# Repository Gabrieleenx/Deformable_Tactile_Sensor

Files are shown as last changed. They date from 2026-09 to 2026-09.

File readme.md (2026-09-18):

# Deformable In-Hand Slip-Aware Tactile Sensor 

This is the material and guides for the paper "Deformable In-Hand Slip-Aware Tactile Sensor with Integrated Velocity Sensing, Force/Torque and Pressure Map Estimation". You can also find a more popular science presentatin on the entire project https://youtu.be/DqMjxcfm4Ek?si=F0FGEtK1jk1I4O4m

This repo is devided into 3 parts: 
1. build files: this is the files and guide to physically build the sensor 
2. embedded code: this is the code that runs on the sensor
3. code on pc: this is the code on the pc that interfaces with the sensor, it also contains the code for calibrating the sensors. 

A 3D printable version of the gripper used can be found at: https://github.com/Gabrieleenx/Parallel_gripper and the fingers to mount the sensors can be found at "/build_files/fingers_cnc", I CNC them from 6061 aluminium on my own CNC, but they could be ordered from PCBWay.

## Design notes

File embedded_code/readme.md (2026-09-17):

# Embedded code

Here is the source code for the tactile sensors, I compiled it with platformio in vs code. It uses the arduino framework, see the .ini file.

In the main file, you can set the name of the sensor, which is usefull if you have multiple of them. Otherwise it is just to flash the sensor and it will start to send out data. If you send 'n' to it will start to print out its name, if you send 's' to it will start to send data again.

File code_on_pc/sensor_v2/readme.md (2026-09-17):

# Code on PC side

This is the part of the project that is the most messy. It is based on ROS Noetic, which is beyond outdated at this point. But the core part of the code for running the sensors has no real dependence on ROS Noetic and can be easily ported to run with anything that suports USB serial and torch. We have already ported it to another framework which is not based on ROS, but not sure when that will see the light of day (not up to me). If I where to use this, I would probaly rewrite this to ROS2 or what ever your lab is using. I never bothered to update, because it worked and it is the very end of my PhD.   

There are a lot of places in the code where you will need to provide paths to models or bags etc... 

## Interfacing with the sensors

Under "/src/sensor_run_time" there is two sets of code to run the sensors. This I included the code that runs a sensor individually and the code that allows multiple of them to run on for example a gripper (https://github.com/Gabrieleenx/Slip-Aware-Object-Manipulation-with-Parallel-Grippers). 

To run the sensors indiviually you have 
```
rosrun sensor_v2 tactile_sensor_node.py
```
which starts the serial communciation with the sensor.
Then the sensor data is mapped to forces and pressure map with:
```
rosrun sensor_v2 tacitle_mapping_node.py
```

For when I ran it on the gripper I used
```
rosrun sensor_v2 sensors_on_gripper.py
```
this also includes the cross sensor compensation. And mapping:
```
rosrun sensor_v2 sensors_mapping_on_gripper.py
```

## Collecting traning data and training 

First don't blindly follow others code when controlling robots, that includes this code. This code does not have many saftey features so don't trust it! It worked for me, but doesn't mean it will work for you. It is essentially just inverse differential kinematics and some trajectory following with force limits/feedback, I would encurage you to write your own version, it is not many lines of code for controlling a UR3e robot. 

This is to collect the data for training, the setup should look like the figure below:

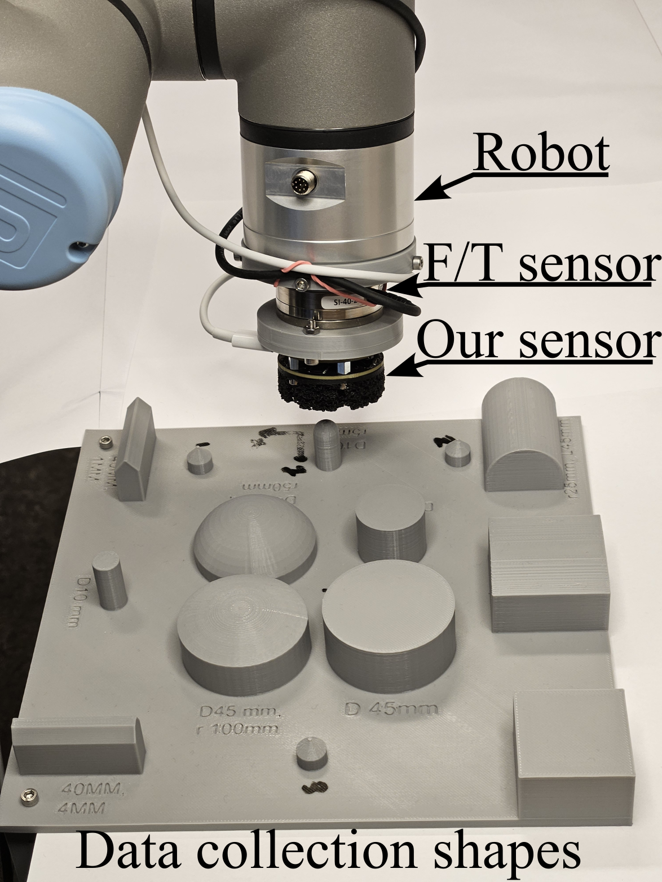
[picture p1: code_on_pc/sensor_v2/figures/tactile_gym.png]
tactile_gym

All 3D printed files are in the bild_files folder. To start the data collection process, there is like robotics classic of 15 scripts to run in terminals. 

```
rosrun rviz rviz -d ~/Documents/Catkin_workspace/catkin_yumi/src/ur_description/launch/ur3_rviz.launch
roslaunch ur_robot_driver ur3e_bringup.launch robot_ip:=192.168.56.3 kinematics_config:=$(rospack find sensor_v2)/etc/robot_calibration.yaml
rosparam load ~/Documents/Catkin_workspace/catkin_yumi/src/sensor_v2/config/ur3_joint_velocity_controller.yaml
rosrun controller_manager spawner --stopped ur3_joint_velocity_controller
rosservice call /controller_manager/switch_controller "{start_controllers: ['ur3_joint_velocity_controller'], stop_controllers: ['scaled_pos_joint_traj_controller'], strictness: 2}"
rosrun netft_utils netft_node --address=192.168.56.5 --sensor_nr=1 # modify to what ever F/T sensors you use, also rezero it!
rosrun sensor_v2 cartesian_velocity_converter_node
roslaunch sensor_v2 tactile_controller.launch 

```

```
rosrun sensor_v2 tactile_sensor_node.py
rosrun sensor_v2 tactile_tf_direct.py
rosrun sensor_v2 calibrate_sensor.py
```
This will ask you to first calibrate the pose, like so:

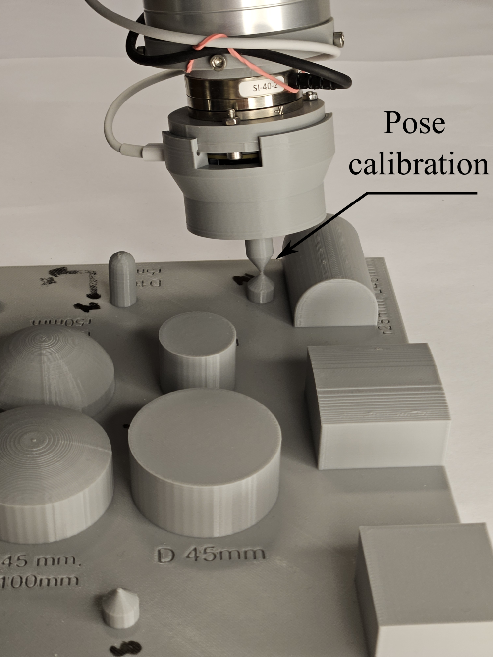
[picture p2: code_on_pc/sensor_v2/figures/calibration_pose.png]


which shows the second calibration pose, 1st is down and 3rd is closest to the camera. This is lead through with the F/T sensor. This will take like 1 hour once started. 

Then do the same to collect the validation data (with fewer pokes).

Once you have two folders with a bunch of bag fiels, we need to extract data and calculate the mesh overlap. This is very so and ineffeicently implemented, so would recomend to do over night. Go to "/data_creation/" and run filter_data.py, and make sure it is pointing to the correct folder with all the data. This will create a data.csv in the folder with the data, do this for both traning and validation foler. 

Then run "filter_out_bad_data.py", it removes some samples that have overlap with no force or the opposie, mby like 30 datapoints in 1900 ish.

We then have the data sets ready for traning a mapping. Under "/learn_mapping/" there is a file called train_mapping.py, point to the training and validation csv files and run the script.

## Calibrate optical sensors

In the mapping scripts there is a sensor config class with the paramters for each optical sensor. These can be found by running calibrate_vel_sensor.py instead of calibrate_sensor.py above. Replace the bag files in "estimate_sensor_pose/data/" with those and run "calculate_sensor_pose.py", this will print out the parameter for each optical sensor. 

I know this is a bit of a messy project and requiers a bit more effort than just run it. But this field of sliding in-hand manipulation is very small and I would not expect many to care to replicate the setup. If that turn out to be wrong, and there is a big interest, then I might try to improve the library.

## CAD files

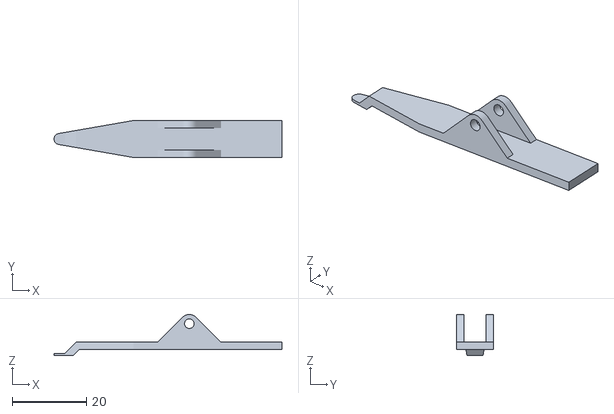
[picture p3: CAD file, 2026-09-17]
build_files/3d_print_files/supporting_files/magnet_place_tool_botom.stl
61.5 x 10.0 x 11.1

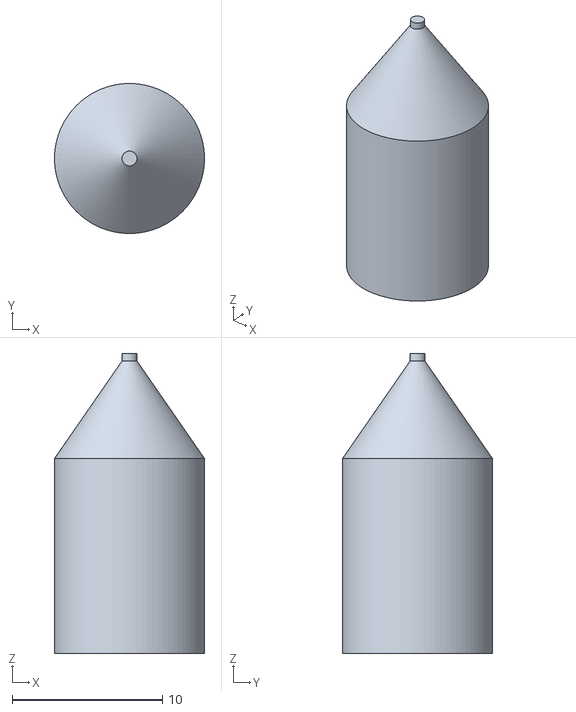
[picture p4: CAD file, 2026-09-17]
build_files/3d_print_files/supporting_files/sensor_v2_data_collection_mount/calibration_tip.stl
10.0 x 10.0 x 20.0

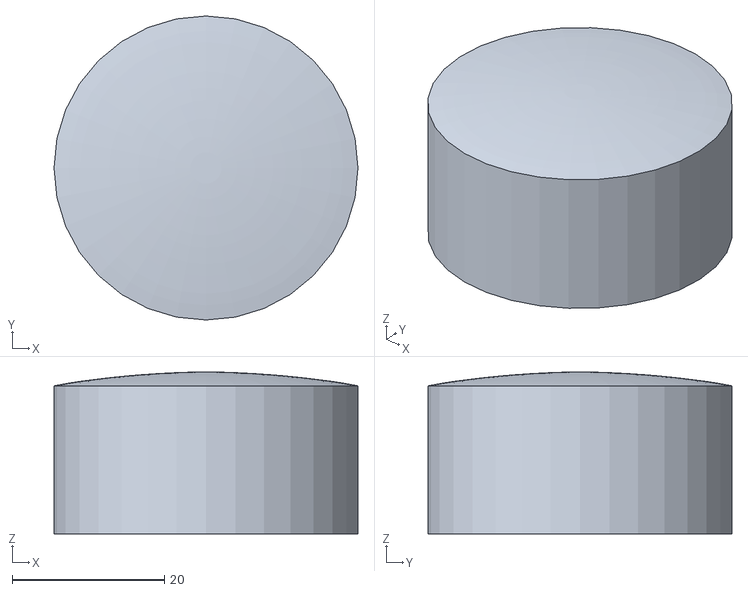
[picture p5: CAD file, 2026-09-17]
code_on_pc/sensor_v2/data_creation/mesh_data/sensor.stl
40.0 x 40.0 x 21.3

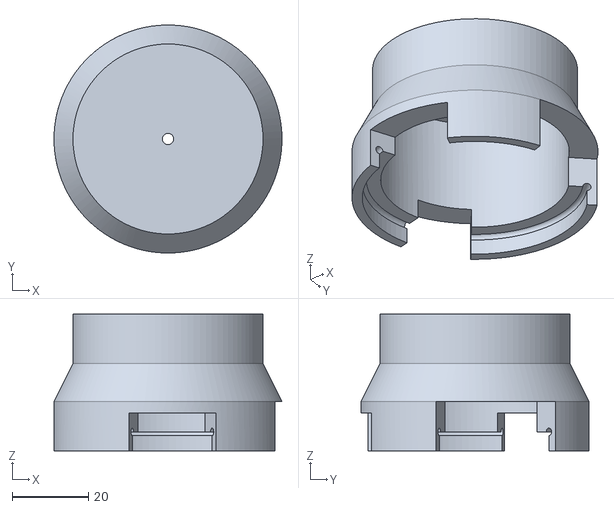
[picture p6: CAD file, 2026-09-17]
build_files/3d_print_files/supporting_files/sensor_v2_data_collection_mount/calibration_sleve.stl
60.0 x 60.0 x 36.0

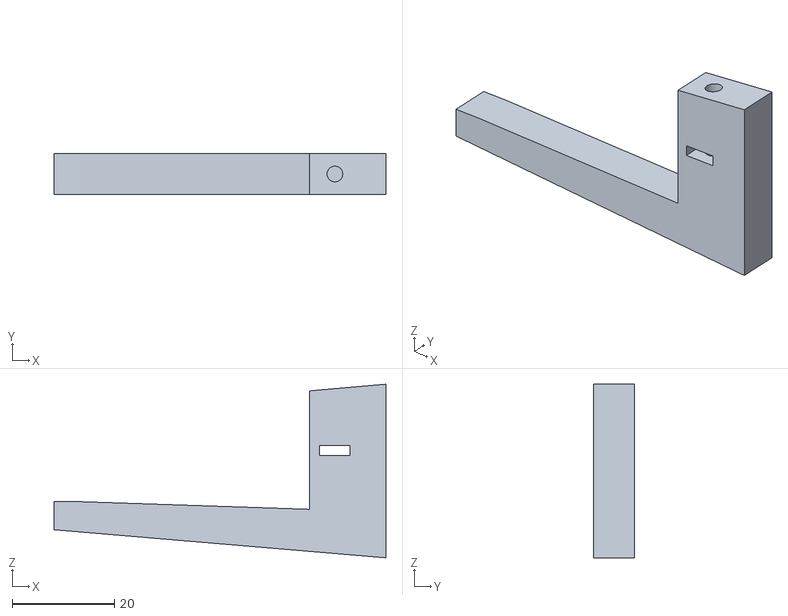
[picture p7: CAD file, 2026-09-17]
build_files/3d_print_files/supporting_files/table_holder.stl
65.0 x 8.00 x 34.0

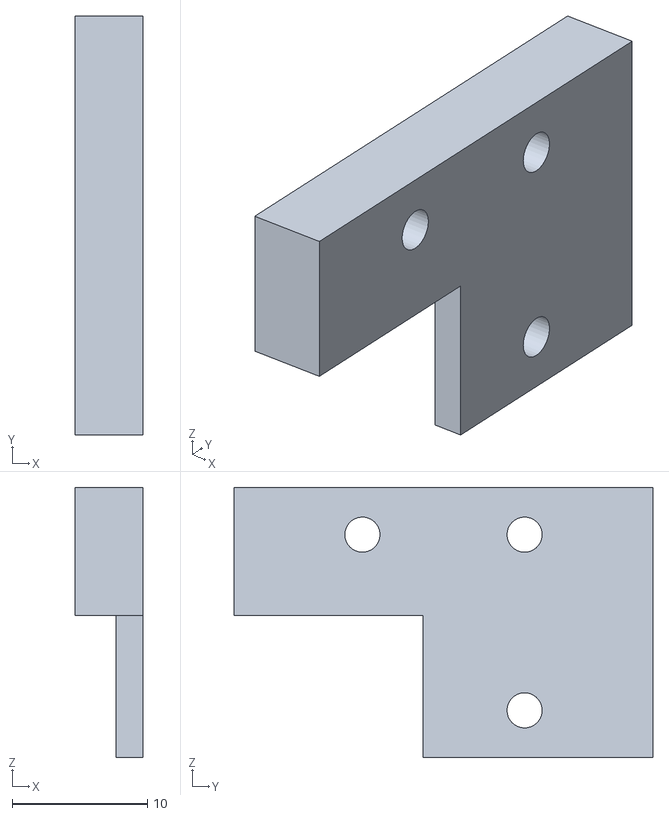
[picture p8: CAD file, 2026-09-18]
build_files/fingers_cnc/finger_sensor_v2_3.stl
5.00 x 31.0 x 20.0

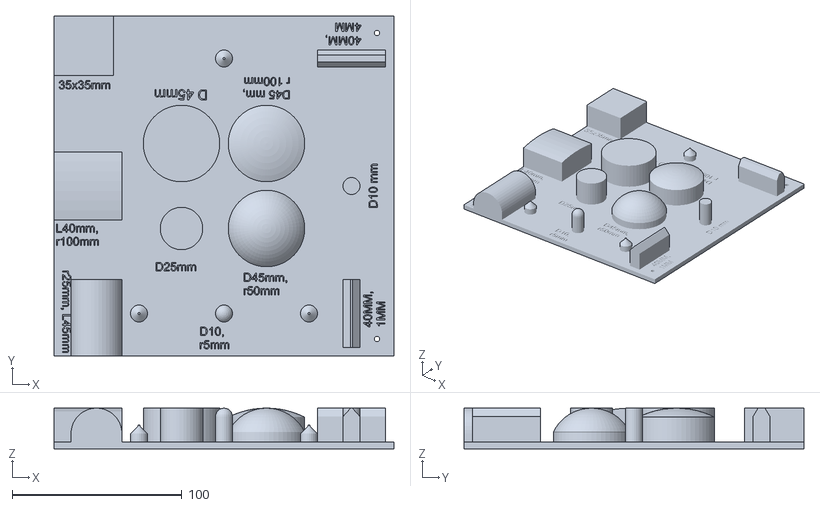
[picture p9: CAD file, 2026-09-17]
code_on_pc/sensor_v2/data_creation/mesh_data/sensor_playground v3.stl
200.0 x 200.0 x 24.0

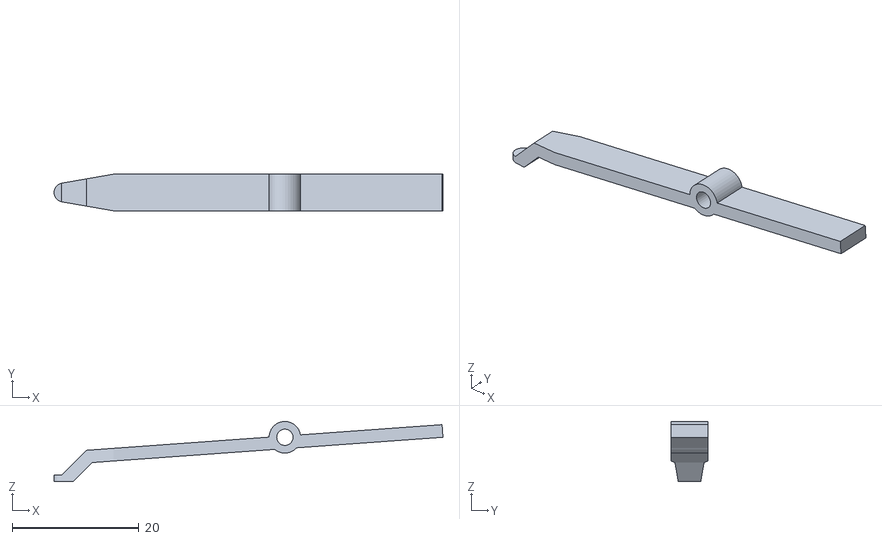
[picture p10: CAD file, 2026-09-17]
build_files/3d_print_files/supporting_files/magnet_place_tool_top.stl
61.5 x 5.80 x 9.50

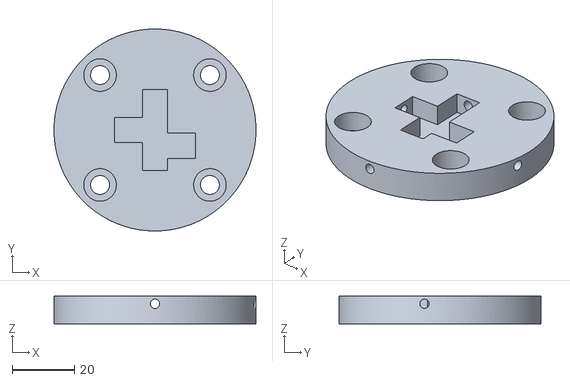
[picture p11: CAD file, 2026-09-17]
build_files/3d_print_files/supporting_files/sensor_v2_data_collection_mount/UR_mount.stl
65.0 x 65.0 x 9.00

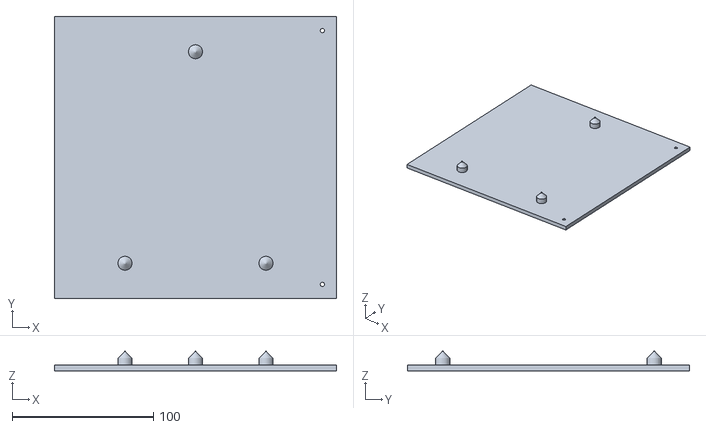
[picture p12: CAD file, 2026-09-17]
code_on_pc/sensor_v2/data_creation/mesh_data/sensor_playground_mouse_flat.stl
200.0 x 200.0 x 14.0

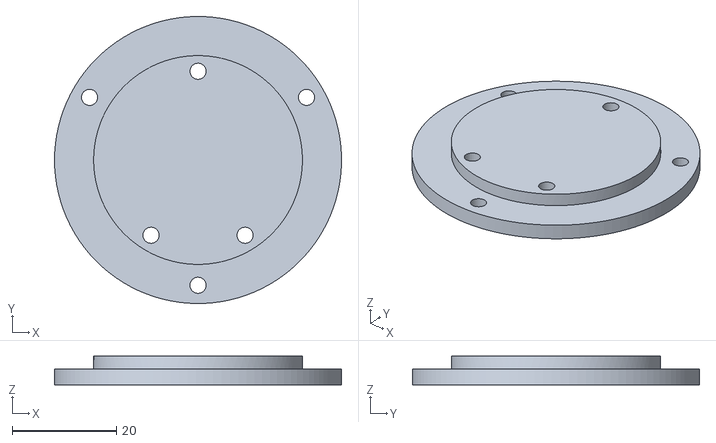
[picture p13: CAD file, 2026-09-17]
build_files/3d_print_files/supporting_files/sensor_v2_data_collection_mount/sensor_ft_mount.stl
55.0 x 55.0 x 5.50

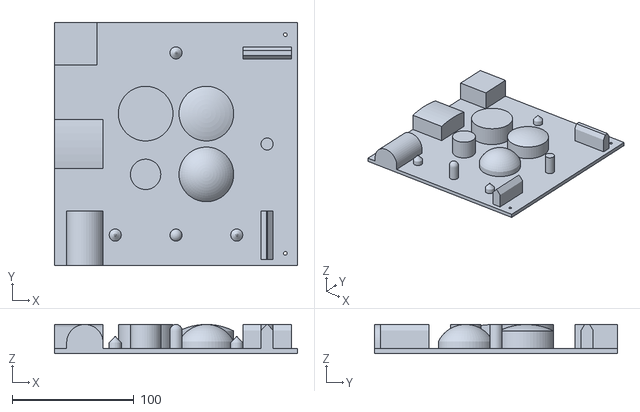
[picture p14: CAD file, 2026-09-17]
build_files/3d_print_files/supporting_files/training_playground.stl
200.0 x 200.0 x 24.0

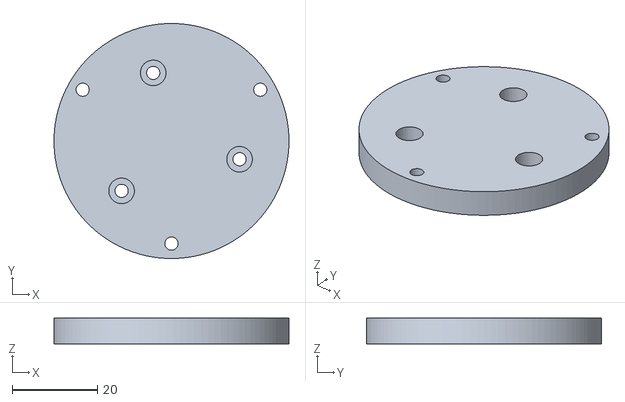
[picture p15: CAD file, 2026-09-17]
build_files/3d_print_files/supporting_files/sensor_v2_data_collection_mount/FT_sensor_mount.stl
55.0 x 55.0 x 6.00

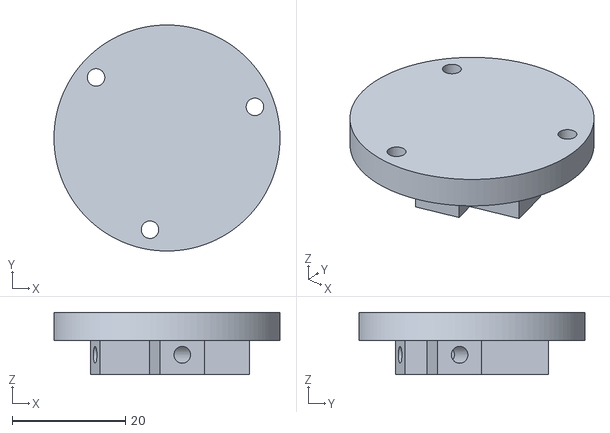
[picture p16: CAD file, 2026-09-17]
build_files/3d_print_files/supporting_files/sensor_v2_data_collection_mount/UR_FT_mount.stl
40.0 x 40.0 x 11.0

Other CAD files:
build_files/fingers_cnc/finger_sensor_v2_1.stl
build_files/fingers_cnc/finger_sensor_v2_2.stl

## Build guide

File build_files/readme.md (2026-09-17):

# Sensor build guide

This is a guide for how to build the sensors. This guide is aimed at people who know how to use tools such as 3D printers, soldering equipment, and basic embedded electronics. This guide is written to a reasonable level of detail, but it is expected that whoever follows it can fill in the gaps.

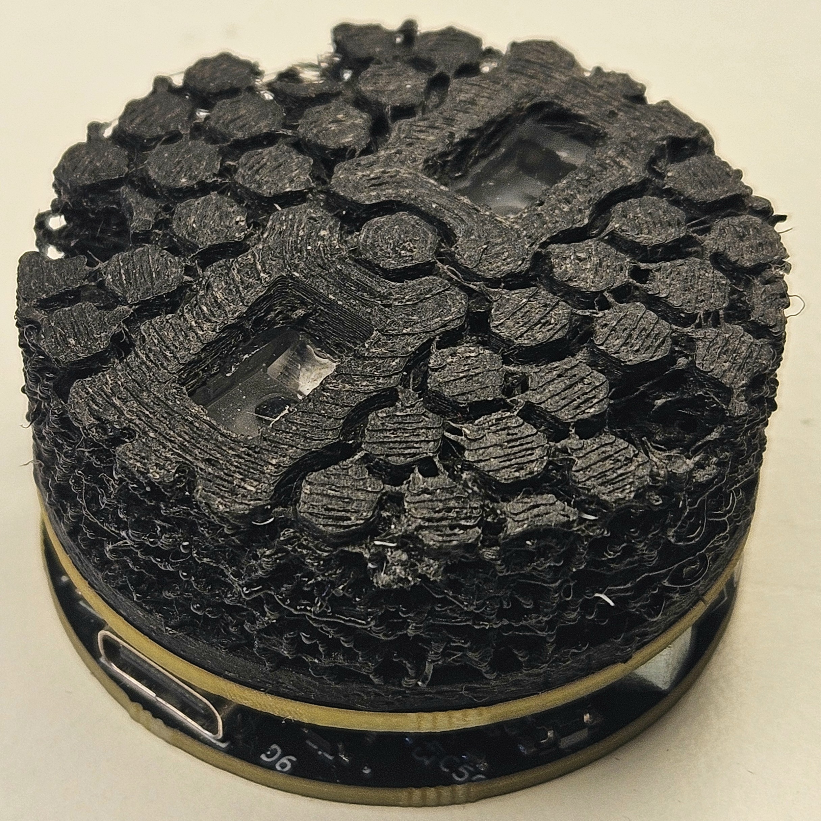
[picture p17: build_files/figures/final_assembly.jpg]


## PCB

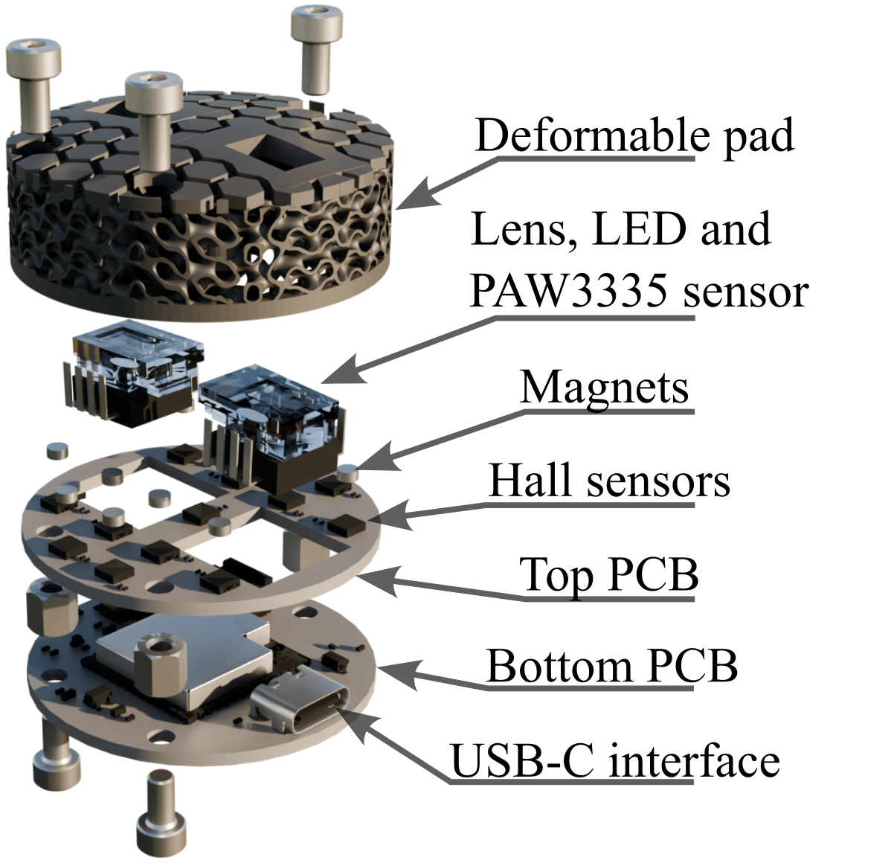
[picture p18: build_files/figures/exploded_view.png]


There are two PCB boards that need to be manufactured. I manufactured them as one board, where they could be broken off from each other. The PCB is manufactured as a 4-layer, double-sided board, with machine assembly. It is not designed for manual assembly, except for attaching the optical sensors, which have to be soldered manually. I used PCBWay to manufacture them; other similar services should also work. Under the PCB subfolder, you will find the files necessary for manufacturing and the BOM. The source KiCad files are also provided.

## Optical sensor unit

Each optical sensor unit consists of the lens, sensor, and LED. The sensor and lens are from the PAW3335DB-TZDU kit. The lens has to be manually cut to a smaller size, as shown in the figure below.

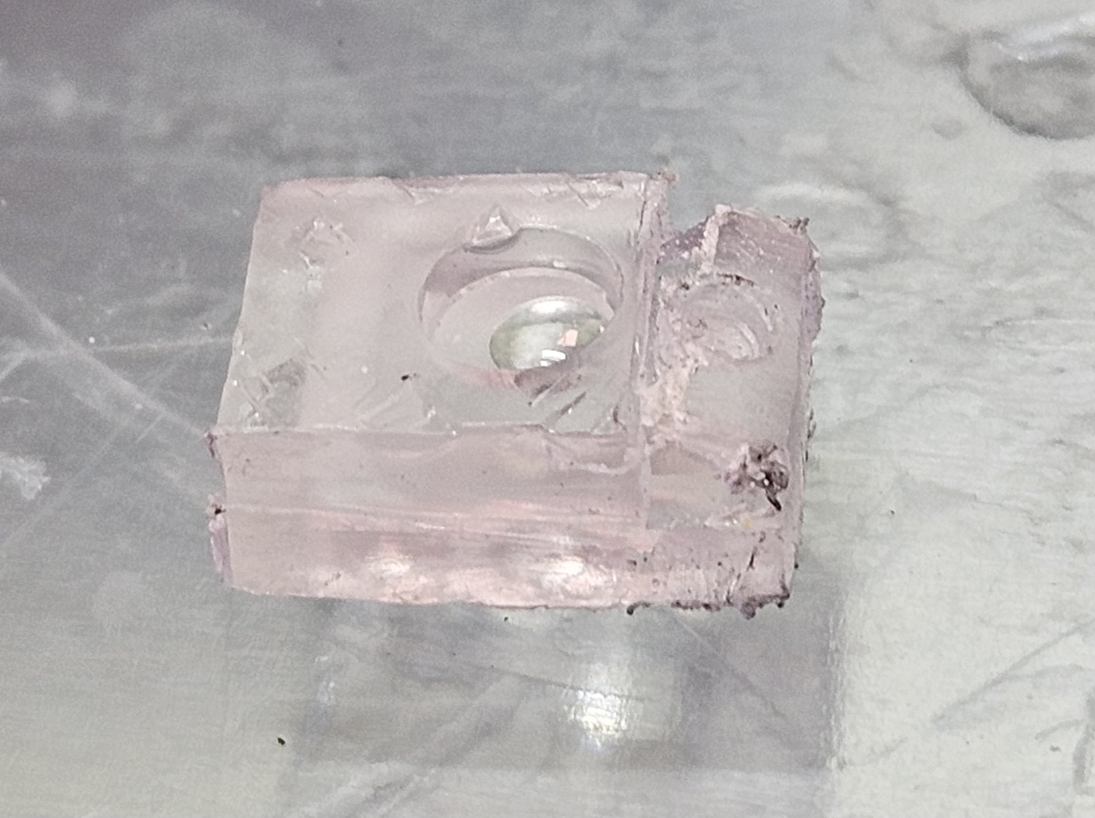
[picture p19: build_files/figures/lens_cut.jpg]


As can be seen, there is also a small hole drilled where the LED will be placed. The hole is approximately 2 mm deep, just enough to fit the dome of the LED cap. The sensor and LED are then glued to the lens with super glue. Make sure that no glue gets close to the optical hole of the sensor. The final result should resemble the illustration below.

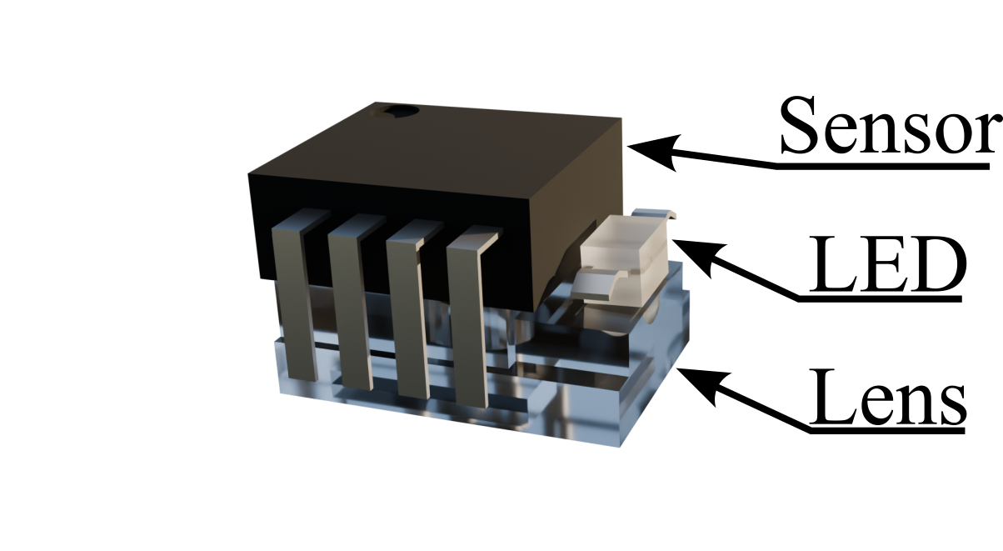
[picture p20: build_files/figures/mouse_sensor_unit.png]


## Printing of contact pad

The contact pad is printed in TPU85 material with 100% infill and PLA as support material. It was printed on a printer that supports multiple printing nozzles (Prusa XL with 5 tool heads). The print is then paused (this can be programmed in PrusaSlicer) when the slots for the magnets are exposed. Twelve N35 magnets, 1 mm thick and 2 mm in diameter, are placed in the slots with a bit of super glue to keep them from jumping out. I put a drop of glue on the side, then dipped the magnet in the drop and placed it into the slot. For this, I printed a tool, essentially a thing with a magnet on it that can open (magnet is glued to top part), to help pick up and place the magnets (see the supporting_files folder). 

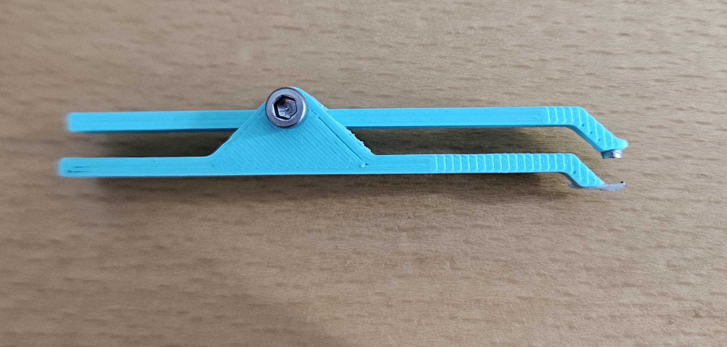
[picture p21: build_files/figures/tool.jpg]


After the magnets have been placed, you should have something like the image below.

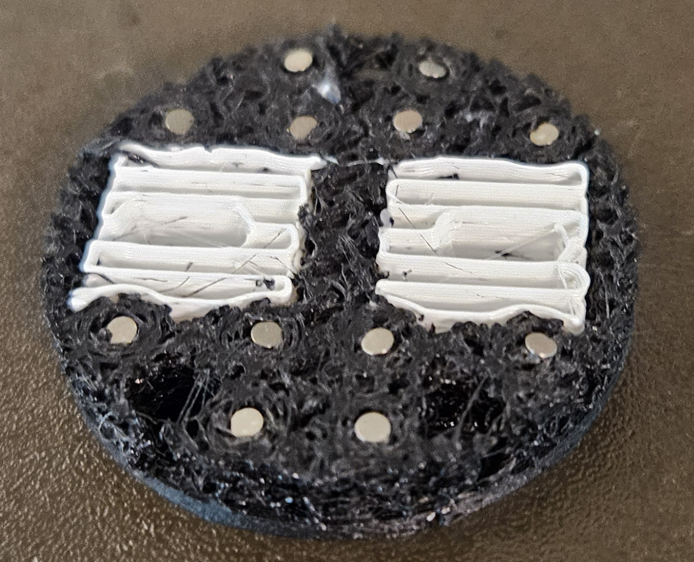
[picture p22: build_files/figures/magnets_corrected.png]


After this, the 3D print can continue until it is completed. The PLA support is then removed, leaving you with the contact pad containing 12 magnets.

## Wiring

Wiring the optical sensors to the top PCB board is probably the most tedious task. We begin by wiring the cables to each of the optical sensor modules, as shown in the figure below.

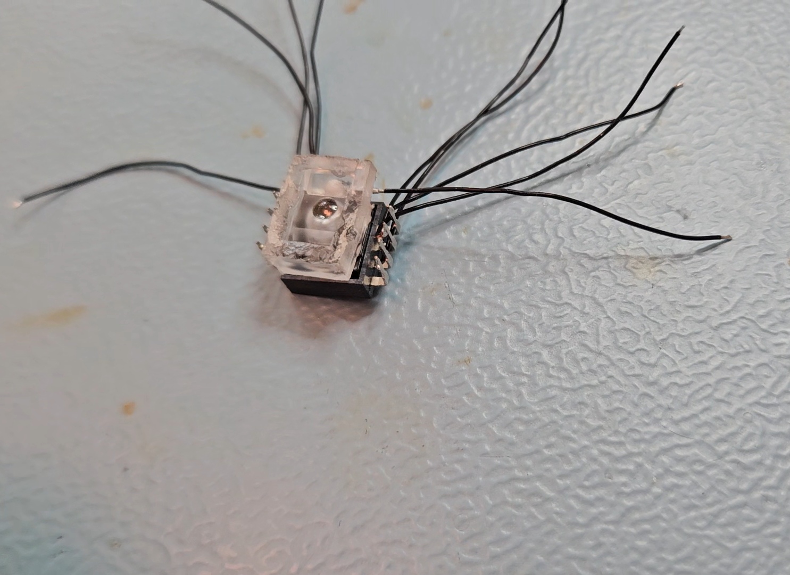
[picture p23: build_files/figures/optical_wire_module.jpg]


It is very important that the correct type of wire is used. It needs to be thin and have a high strand count. If either of these requirements is not met, the cable will either break during repeated bending or it will not be flexible enough to assemble. I use 30 AWG, 49-strand wire. Also, be careful not to damage the sensor during soldering.

Then, I mark all the cables and place them in the contact pad, as shown below. I add a bit of glue to make sure the sensor won't fall out during operation.

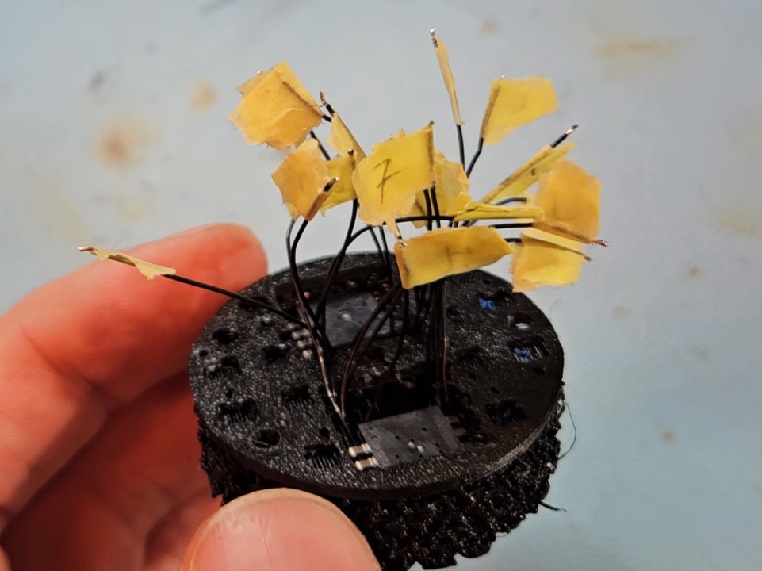
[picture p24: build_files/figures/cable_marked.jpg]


Then the top PCB can be placed.

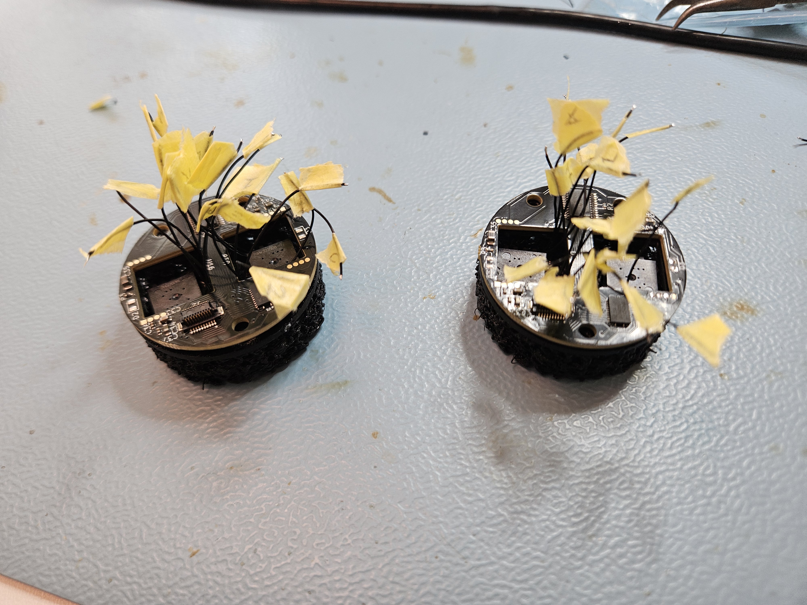
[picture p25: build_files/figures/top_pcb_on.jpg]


Finally, solder all the cables. Be careful to solder them correctly, as it is a bit confusing. I used a laptop with KiCad and the datasheets open to find the correct pin matching. Just remember that you are viewing the design from the opposite direction in KiCad. The end result should look something like this:

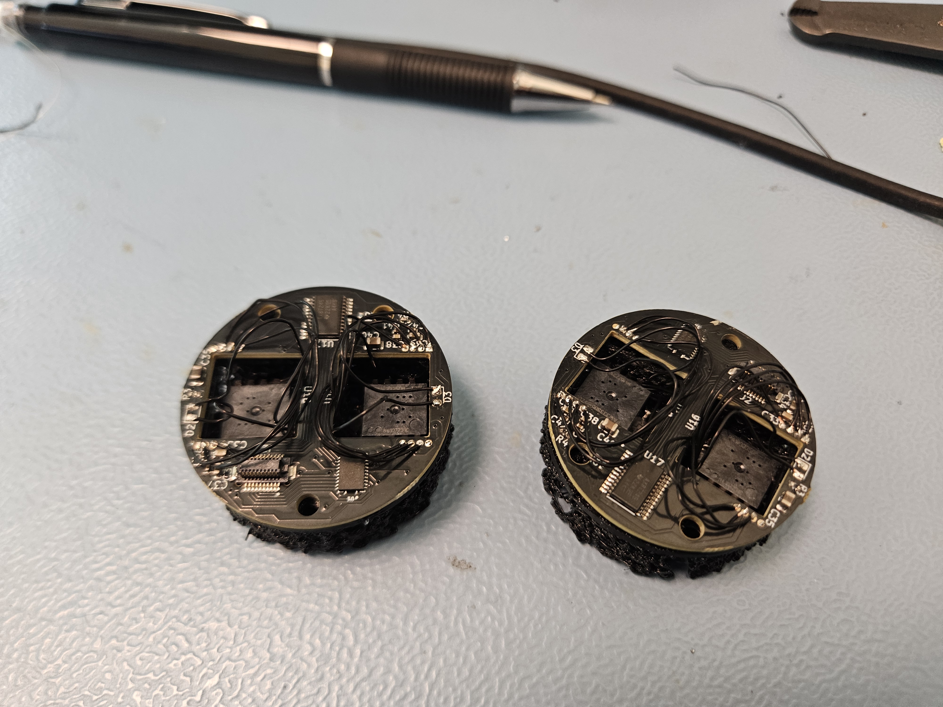
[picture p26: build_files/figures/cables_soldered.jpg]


## Assembly



The final assembly is very simple. You will need three M3 spacers, 5 mm, ([Würth Elektronik 970050366](https://www.mouser.se/en/ProductDetail/Wurth-Elektronik/970050366?qs=wr8lucFkNMUPheOXmFZsfA%3D%3D)) spacers and six M3 screws. I think the top M3 screws are 6 mm long, and the length of the bottom screws will depend on what the assembly will be mounted on. The important thing is that the M3 screws can both fit into the spacers.

And you have your final assembly:



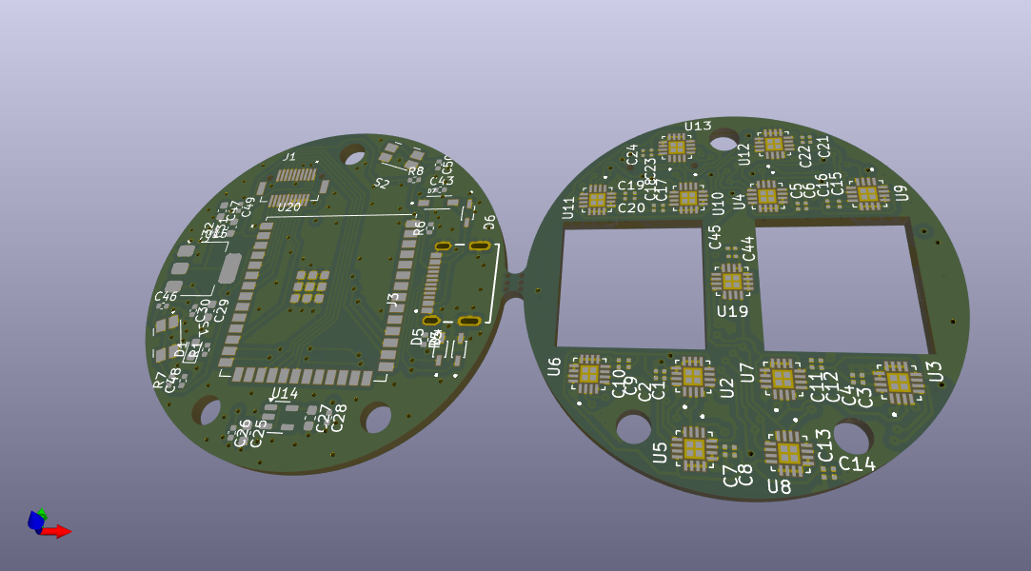
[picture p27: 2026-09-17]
build_files/PCB/manifacturing_files/3d_view.png

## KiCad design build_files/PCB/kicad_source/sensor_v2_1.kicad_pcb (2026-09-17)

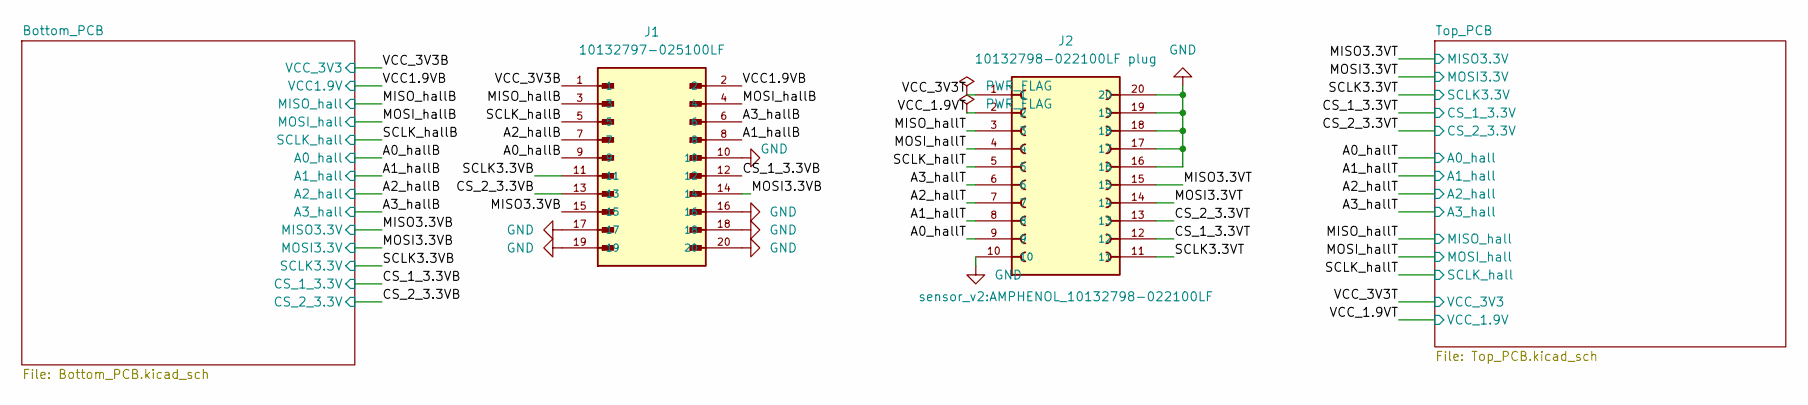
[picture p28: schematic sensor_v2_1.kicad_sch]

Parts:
J1: 10132797-025100LF; AMPHENOL_10132797-025100LF; PARTREV F
J2: 10132798-022100LF plug; AMPHENOL_10132798-022100LF; PARTREV F

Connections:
/A0_hallB: J1.9; also elsewhere on the board
/A0_hallT: J2.9; also elsewhere on the board
/A1_hallB: J1.8; also elsewhere on the board
/A1_hallT: J2.8; also elsewhere on the board
/A2_hallB: J1.7; also elsewhere on the board
/A2_hallT: J2.7; also elsewhere on the board
/A3_hallB: J1.6; also elsewhere on the board
/A3_hallT: J2.6; also elsewhere on the board
/CS_1_3.3VB: J1.12; also elsewhere on the board
/CS_1_3.3VT: J2.12; also elsewhere on the board
/CS_2_3.3VB: J1.13; also elsewhere on the board
/CS_2_3.3VT: J2.13; also elsewhere on the board
/MISO3.3VB: J1.15; also elsewhere on the board
/MISO3.3VT: J2.15; also elsewhere on the board
/MISO_hallB: J1.3; also elsewhere on the board
/MISO_hallT: J2.3; also elsewhere on the board
/MOSI3.3VB: J1.14; also elsewhere on the board
/MOSI3.3VT: J2.14; also elsewhere on the board
/MOSI_hallB: J1.4; also elsewhere on the board
/MOSI_hallT: J2.4; also elsewhere on the board
/SCLK3.3VB: J1.11; also elsewhere on the board
/SCLK3.3VT: J2.11; also elsewhere on the board
/SCLK_hallB: J1.5; also elsewhere on the board
/SCLK_hallT: J2.5; also elsewhere on the board
/VCC1.9VB: J1.2; also elsewhere on the board
/VCC_1.9VT: J2.2; also elsewhere on the board
/VCC_3V3B: J1.1; also elsewhere on the board
/VCC_3V3T: J2.1; also elsewhere on the board
GND: J1.10, J1.16, J1.17, J1.18, J1.19, J1.20, J2.10, J2.16, J2.17, J2.18, J2.19, J2.20; also elsewhere on the board

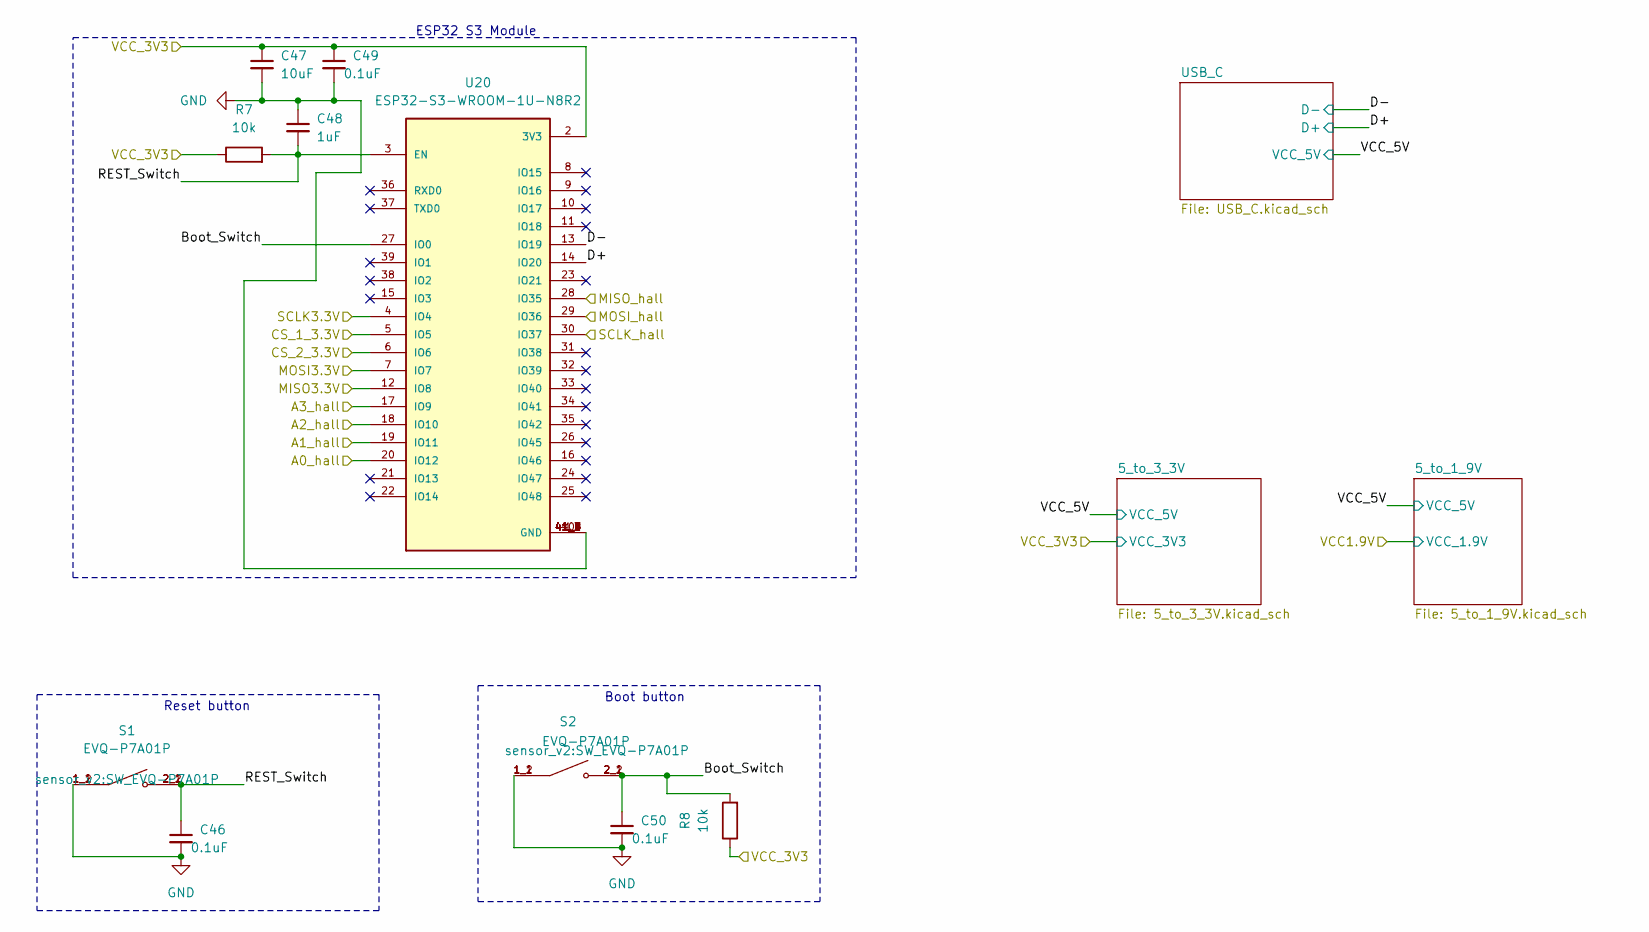
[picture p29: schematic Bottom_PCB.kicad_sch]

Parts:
C46, C49, C50: 0.1uF; C_0402_1005Metric; Manifacturer Part Number MLASE105SB7104KFNA01
C47: 10uF; C_0603_1608Metric; Manifacturer Part Number CL10A106KP8NQSC
C48: 1uF; C_0402_1005Metric; Manifacturer Part Number MCASE105SB5105KFNA1J
R7, R8: 10k; R_0402_1005Metric; Manifacturer Part Number TNPW040210K0BHED
S1, S2: EVQ-P7A01P; SW_EVQ-P7A01P; Manifacturer Part Number EVQ-P7A01P
U20: ESP32-S3-WROOM-1U-N8R2; XCVR_ESP32-S3-WROOM-1U-N8R2; PARTREV v1.1

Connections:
/A0_hallB: U20.20 (IO12); also elsewhere on the board
/A1_hallB: U20.19 (IO11); also elsewhere on the board
/A2_hallB: U20.18 (IO10); also elsewhere on the board
/A3_hallB: U20.17 (IO9); also elsewhere on the board
/Bottom_PCB/Boot_Switch: C50.1, R8.2, S2.2_1, S2.2_2, U20.27 (IO0)
/Bottom_PCB/D+: U20.14 (IO20); also elsewhere on the board
/Bottom_PCB/D-: U20.13 (IO19); also elsewhere on the board
/Bottom_PCB/REST_Switch: C46.1, C48.2, R7.2, S1.2_1, S1.2_2, U20.3 (EN)
/CS_1_3.3VB: U20.5 (IO5); also elsewhere on the board
/CS_2_3.3VB: U20.6 (IO6); also elsewhere on the board
/MISO3.3VB: U20.12 (IO8); also elsewhere on the board
/MISO_hallB: U20.28 (IO35); also elsewhere on the board
/MOSI3.3VB: U20.7 (IO7); also elsewhere on the board
/MOSI_hallB: U20.29 (IO36); also elsewhere on the board
/SCLK3.3VB: U20.4 (IO4); also elsewhere on the board
/SCLK_hallB: U20.30 (IO37); also elsewhere on the board
/VCC_3V3B: C47.1, C49.1, R7.1, R8.1, U20.2 (3V3); also elsewhere on the board
GND: C46.2, C47.2, C48.1, C49.2, C50.2, S1.1_1, S1.1_2, S2.1_1, S2.1_2, U20.1 (GND), U20.40 (GND), U20.41_1 (GND), U20.41_2 (GND), U20.41_3 (GND), U20.41_4 (GND), U20.41_5 (GND), U20.41_6 (GND), U20.41_7 (GND), U20.41_8 (GND), U20.41_9 (GND); also elsewhere on the board

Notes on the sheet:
ESP32 S3 Module
Reset button
Boot button

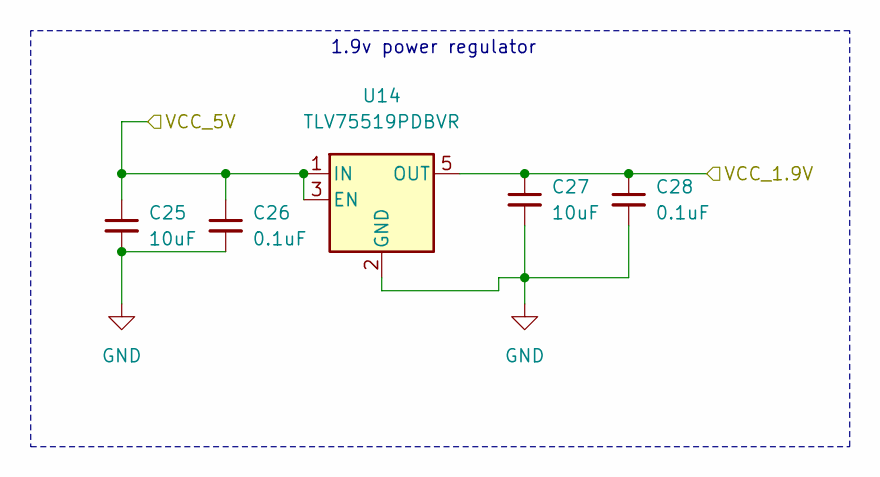
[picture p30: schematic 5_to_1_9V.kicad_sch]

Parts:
C25, C27: 10uF; C_0603_1608Metric; Manifacturer Part Number CL10A106KP8NQSC
C26, C28: 0.1uF; C_0402_1005Metric; Manifacturer Part Number MLASE105SB7104KFNA01
U14: TLV75519PDBVR; SOT-23-5; Manifacturer Part Number TLV75519PDBVR

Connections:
/Bottom_PCB/VCC_5V: C25.1, C26.1, U14.1 (IN), U14.3 (EN); also elsewhere on the board
/VCC1.9VB: C27.1, C28.1, U14.5 (OUT); also elsewhere on the board
GND: C25.2, C26.2, C27.2, C28.2, U14.2 (GND); also elsewhere on the board

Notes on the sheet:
1.9v power regulator

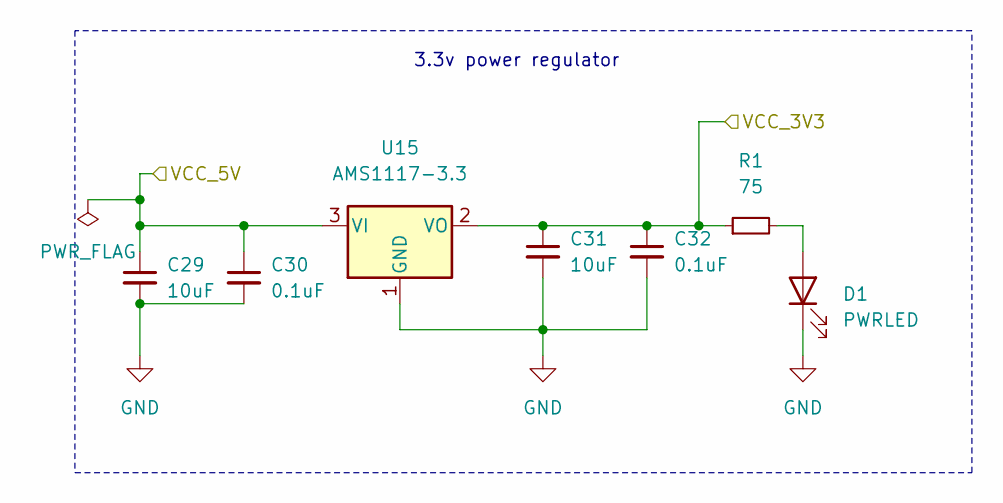
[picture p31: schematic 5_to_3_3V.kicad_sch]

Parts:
C29, C31: 10uF; C_0603_1608Metric; Manifacturer Part Number CL10A106KP8NQSC
C30, C32: 0.1uF; C_0402_1005Metric; Manifacturer Part Number MLASE105SB7104KFNA01
D1: PWRLED; LED_0603_1608Metric; Manifacturer Part Number KO EELP41.22-Q1S2-25-A8J8-020-R18
R1: 75; R_0402_1005Metric; Manifacturer Part Number RT0402FRE0775RL
U15: AMS1117-3.3; SOT-223-3_TabPin2; Manifacturer Part Number AMS1117-3.3

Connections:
/Bottom_PCB/VCC_5V: C29.1, C30.1, U15.3 (VI); also elsewhere on the board
/VCC_3V3B: C31.1, C32.1, R1.1, U15.2 (VO); also elsewhere on the board
GND: C29.2, C30.2, C31.2, C32.2, D1.1 (K), U15.1 (GND); also elsewhere on the board
unnamed: D1.2 (A), R1.2

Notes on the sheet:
3.3v power regulator

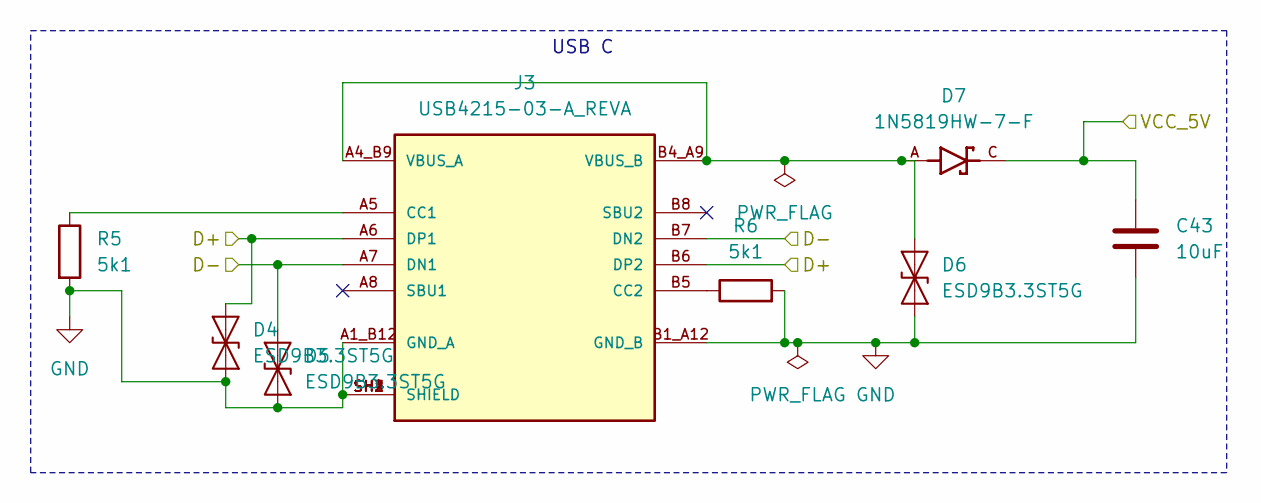
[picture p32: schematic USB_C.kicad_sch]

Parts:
C43: 10uF; C_0402_1005Metric; Manifacturer Part Number CL05A106MP8NUB8
D4, D5, D6: ESD9B3.3ST5G; SOD2513X120N; Manifacturer Part Number DESD5V0S1BA-7
D7: 1N5819HW-7-F; SOD3715X145N; PARTREV 18-2
J3: USB4215-03-A_REVA; GCT_USB4215-03-A_REVA; PARTREV A
R5, R6: 5k1; R_0402_1005Metric; Manifacturer Part Number MCS04020C5101FE000

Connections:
/Bottom_PCB/D+: D4.1 (A1), J3.A6 (DP1), J3.B6 (DP2); also elsewhere on the board
/Bottom_PCB/D-: D5.1 (A1), J3.A7 (DN1), J3.B7 (DN2); also elsewhere on the board
/Bottom_PCB/VCC_5V: C43.1, D7.C; also elsewhere on the board
GND: C43.2, D4.2 (A2), D5.2 (A2), D6.1 (A1), J3.A1_B12 (GND_A), J3.B1_A12 (GND_B), J3.SH1 (SHIELD), J3.SH2 (SHIELD), J3.SH3 (SHIELD), J3.SH4 (SHIELD), R5.2, R6.2; also elsewhere on the board
unnamed: D6.2 (A2), D7.A, J3.A4_B9 (VBUS_A), J3.B4_A9 (VBUS_B)
unnamed: J3.A5 (CC1), R5.1
unnamed: J3.B5 (CC2), R6.1

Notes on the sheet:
USB C

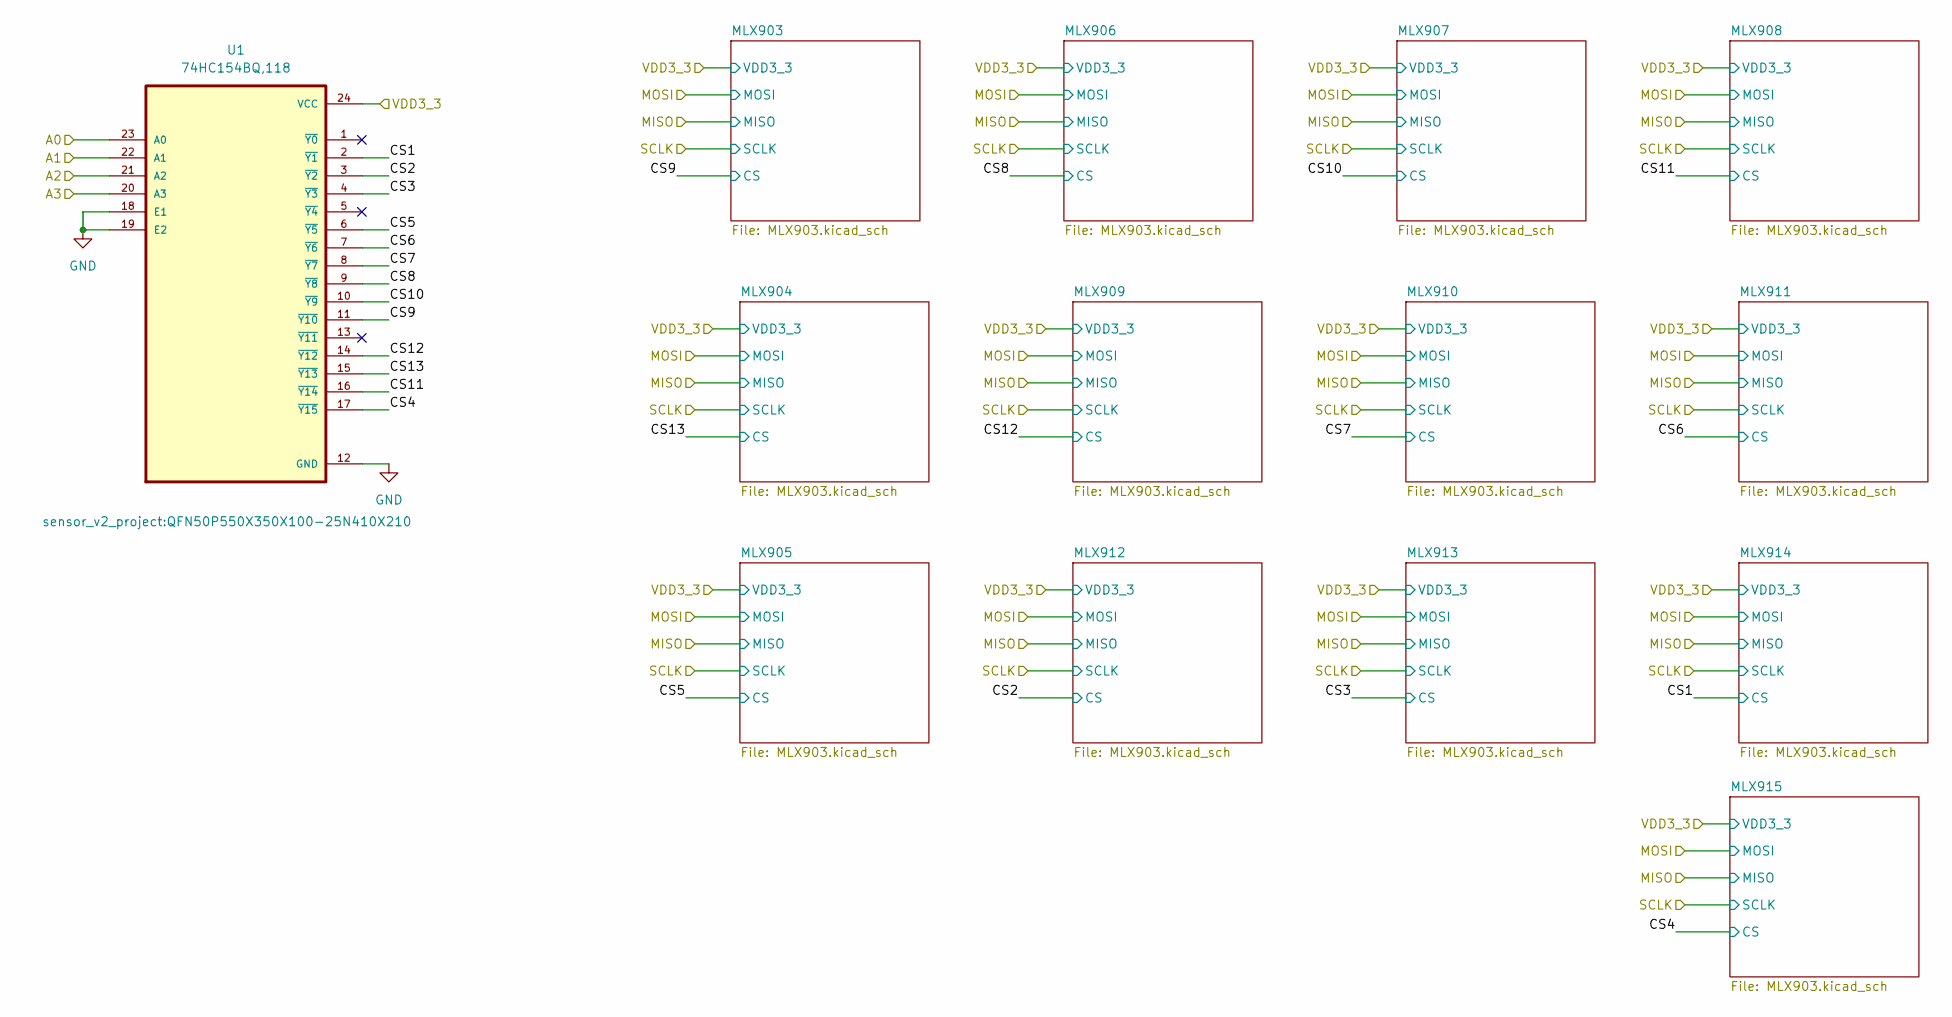
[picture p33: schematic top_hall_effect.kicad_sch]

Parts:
U1: 74HC154BQ,118; QFN50P550X350X100-25N410X210; Manifacturer Part Number 74HC154BQ,118

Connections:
/A0_hallT: U1.23 (A0); also elsewhere on the board
/A1_hallT: U1.22 (A1); also elsewhere on the board
/A2_hallT: U1.21 (A2); also elsewhere on the board
/A3_hallT: U1.20 (A3); also elsewhere on the board
/Top_PCB/top_hall_effect/CS1: U1.2 (~Y1); also elsewhere on the board
/Top_PCB/top_hall_effect/CS2: U1.3 (~Y2); also elsewhere on the board
/Top_PCB/top_hall_effect/CS3: U1.4 (~Y3); also elsewhere on the board
/Top_PCB/top_hall_effect/CS4: U1.17 (~Y15); also elsewhere on the board
/Top_PCB/top_hall_effect/CS5: U1.6 (~Y5); also elsewhere on the board
/Top_PCB/top_hall_effect/CS6: U1.7 (~Y6); also elsewhere on the board
/Top_PCB/top_hall_effect/CS7: U1.8 (~Y7); also elsewhere on the board
/Top_PCB/top_hall_effect/CS8: U1.9 (~Y8); also elsewhere on the board
/Top_PCB/top_hall_effect/CS9: U1.11 (~Y10); also elsewhere on the board
/Top_PCB/top_hall_effect/CS10: U1.10 (~Y9); also elsewhere on the board
/Top_PCB/top_hall_effect/CS11: U1.16 (~Y14); also elsewhere on the board
/Top_PCB/top_hall_effect/CS12: U1.14 (~Y12); also elsewhere on the board
/Top_PCB/top_hall_effect/CS13: U1.15 (~Y13); also elsewhere on the board
/VCC_3V3T: U1.24 (VCC); also elsewhere on the board
GND: U1.12 (GND), U1.18 (E1), U1.19 (E2); also elsewhere on the board

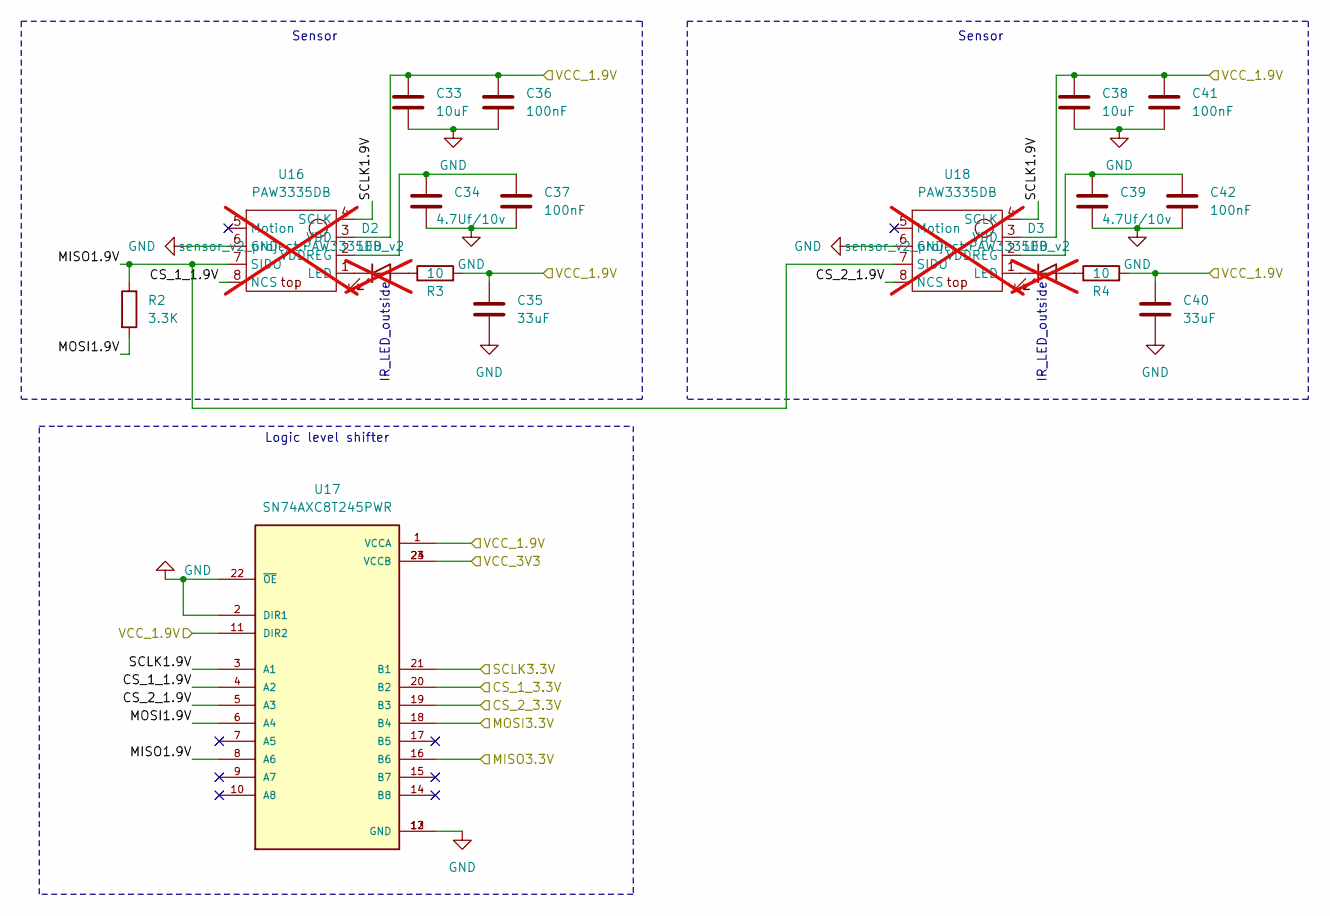
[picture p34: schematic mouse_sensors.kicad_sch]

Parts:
C33: 10uF; C_0603_1608Metric; Manifacturer Part Number CL10A106KP8NQSC
C34, C39: 4.7Uf/10v; C_0603_1608Metric; Manifacturer Part Number LMK107BJ475KA-T
C35, C40: 33uF; C_0805_2012Metric; Manifacturer Part Number C2012X5R1A336M125AC
C36, C37, C41, C42: 100nF; C_0402_1005Metric; Manifacturer Part Number MLAST105SB5104KFNA01
C38: 10uF; C_0402_1005Metric; Manifacturer Part Number CL05A106MP8NUB8
D2, D3: LED; LED_0805_2012Metric; Manifacturer Part Number TSMF1030; not fitted
R2: 3.3K; R_0402_1005Metric; Manifacturer Part Number MCS0402MD3301BE000
R3, R4: 10; R_0402_1005Metric; Manifacturer Part Number ERA-2AKD100X
U16, U18: PAW3335DB; PAW3335DB_v2; Manifacturer Part Number No assembly; not fitted
U17: SN74AXC8T245PWR; SOP65P640X120-24N; PARTREV August 2018; DigiKey_Part_Number 296-48831-2-ND

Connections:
/CS_1_3.3VT: U17.20 (B2); also elsewhere on the board
/CS_2_3.3VT: U17.19 (B3); also elsewhere on the board
/MISO3.3VT: U17.16 (B6); also elsewhere on the board
/MOSI3.3VT: U17.18 (B4); also elsewhere on the board
/SCLK3.3VT: U17.21 (B1); also elsewhere on the board
/Top_PCB/mouse_sensors/CS_1_1.9V: U16.8 (NCS), U17.4 (A2)
/Top_PCB/mouse_sensors/CS_2_1.9V: U17.5 (A3), U18.8 (NCS)
/Top_PCB/mouse_sensors/MISO1.9V: R2.1, U16.7 (SIDO), U17.8 (A6), U18.7 (SIDO)
/Top_PCB/mouse_sensors/MOSI1.9V: R2.2, U17.6 (A4)
/Top_PCB/mouse_sensors/SCLK1.9V: U16.4 (SCLK), U17.3 (A1), U18.4 (SCLK)
/VCC_1.9VT: C33.1, C35.1, C36.1, C38.1, C40.1, C41.1, R3.2, R4.2, U16.3 (VDD), U17.1 (VCCA), U17.11 (DIR2), U18.3 (VDD); also elsewhere on the board
/VCC_3V3T: U17.23 (VCCB), U17.24 (VCCB); also elsewhere on the board
GND: C33.2, C34.2, C35.2, C36.2, C37.2, C38.2, C39.2, C40.2, C41.2, C42.2, U16.6 (GND), U17.2 (DIR1), U17.12 (GND), U17.13 (GND), U17.22 (~OE), U18.6 (GND); also elsewhere on the board
unnamed: D2.2 (A), R3.1
unnamed: D2.1 (K), U16.1 (LED)
unnamed: D3.2 (A), R4.1
unnamed: D3.1 (K), U18.1 (LED)
unnamed: C34.1, C37.1, U16.2 (VDDREG)
unnamed: C39.1, C42.1, U18.2 (VDDREG)

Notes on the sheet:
Logic level shifter
Sensor
IR_LED_outside

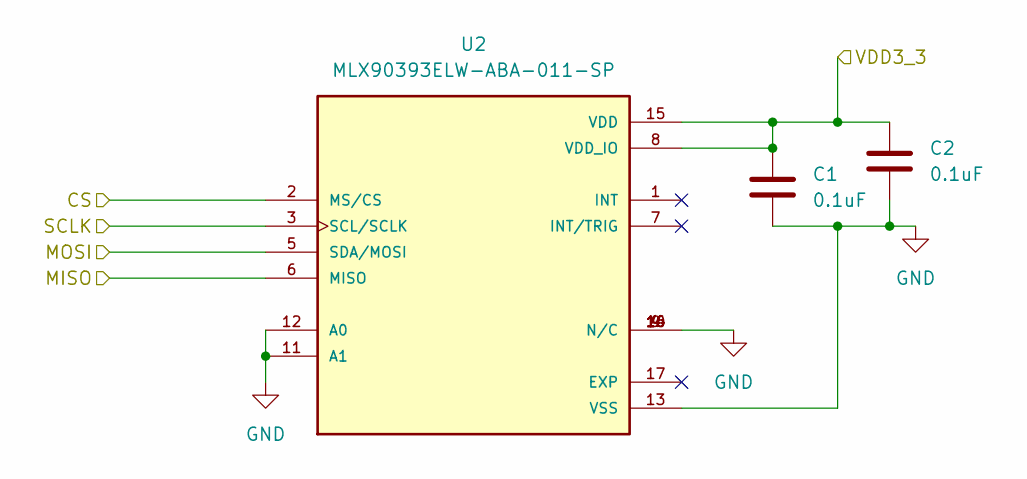
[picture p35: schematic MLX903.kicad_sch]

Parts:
C1, C2: 0.1uF; C_0201_0603Metric; Manifacturer Part Number EMK063BJ104KP-F
U2: MLX90393ELW-ABA-011-SP; QFN50P300X300X100-17N; PARTREV 010

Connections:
/MISO_hallT: U2.6 (MISO); also elsewhere on the board
/MOSI_hallT: U2.5 (SDA/MOSI); also elsewhere on the board
/SCLK_hallT: U2.3 (SCL/SCLK); also elsewhere on the board
/Top_PCB/top_hall_effect/CS9: U2.2 (MS/CS); also elsewhere on the board
/VCC_3V3T: C1.1, C2.1, U2.8 (VDD_IO), U2.15 (VDD); also elsewhere on the board
GND: C1.2, C2.2, U2.4 (N/C), U2.9 (N/C), U2.10 (N/C), U2.11 (A1), U2.12 (A0), U2.13 (VSS), U2.14 (N/C), U2.16 (N/C); also elsewhere on the board

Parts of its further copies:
C3, C4, C5, C6, C7, C8, C9, C10, C11, C12, C13, C14, C15, C16, C17, C18, C19, C20, C21, C22, C23, C24, C44, C45: 0.1uF; C_0201_0603Metric; Manifacturer Part Number EMK063BJ104KP-F
U3, U4, U5, U6, U7, U8, U9, U10, U11, U12, U13, U19: MLX90393ELW-ABA-011-SP; QFN50P300X300X100-17N; PARTREV 010

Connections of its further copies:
/MISO_hallT: U3.6 (MISO), U4.6 (MISO), U5.6 (MISO), U6.6 (MISO), U7.6 (MISO), U8.6 (MISO), U9.6 (MISO), U10.6 (MISO), U11.6 (MISO), U12.6 (MISO), U13.6 (MISO), U19.6 (MISO); also elsewhere on the board
/MOSI_hallT: U3.5 (SDA/MOSI), U4.5 (SDA/MOSI), U5.5 (SDA/MOSI), U6.5 (SDA/MOSI), U7.5 (SDA/MOSI), U8.5 (SDA/MOSI), U9.5 (SDA/MOSI), U10.5 (SDA/MOSI), U11.5 (SDA/MOSI), U12.5 (SDA/MOSI), U13.5 (SDA/MOSI), U19.5 (SDA/MOSI); also elsewhere on the board
/SCLK_hallT: U3.3 (SCL/SCLK), U4.3 (SCL/SCLK), U5.3 (SCL/SCLK), U6.3 (SCL/SCLK), U7.3 (SCL/SCLK), U8.3 (SCL/SCLK), U9.3 (SCL/SCLK), U10.3 (SCL/SCLK), U11.3 (SCL/SCLK), U12.3 (SCL/SCLK), U13.3 (SCL/SCLK), U19.3 (SCL/SCLK); also elsewhere on the board
/Top_PCB/top_hall_effect/CS1: U13.2 (MS/CS); also elsewhere on the board
/Top_PCB/top_hall_effect/CS2: U10.2 (MS/CS); also elsewhere on the board
/Top_PCB/top_hall_effect/CS3: U11.2 (MS/CS); also elsewhere on the board
/Top_PCB/top_hall_effect/CS4: U19.2 (MS/CS); also elsewhere on the board
/Top_PCB/top_hall_effect/CS5: U12.2 (MS/CS); also elsewhere on the board
/Top_PCB/top_hall_effect/CS6: U9.2 (MS/CS); also elsewhere on the board
/Top_PCB/top_hall_effect/CS7: U4.2 (MS/CS); also elsewhere on the board
/Top_PCB/top_hall_effect/CS8: U5.2 (MS/CS); also elsewhere on the board
/Top_PCB/top_hall_effect/CS10: U6.2 (MS/CS); also elsewhere on the board
/Top_PCB/top_hall_effect/CS11: U7.2 (MS/CS); also elsewhere on the board
/Top_PCB/top_hall_effect/CS12: U3.2 (MS/CS); also elsewhere on the board
/Top_PCB/top_hall_effect/CS13: U8.2 (MS/CS); also elsewhere on the board
/VCC_3V3T: C3.1, C4.1, C5.1, C6.1, C7.1, C8.1, C9.1, C10.1, C11.1, C12.1, C13.1, C14.1, C15.1, C16.1, C17.1, C18.1, C19.1, C20.1, C21.1, C22.1, C23.1, C24.1, C44.1, C45.1, U3.8 (VDD_IO), U3.15 (VDD), U4.8 (VDD_IO), U4.15 (VDD), U5.8 (VDD_IO), U5.15 (VDD), U6.8 (VDD_IO), U6.15 (VDD), U7.8 (VDD_IO), U7.15 (VDD), U8.8 (VDD_IO), U8.15 (VDD), U9.8 (VDD_IO), U9.15 (VDD), U10.8 (VDD_IO), U10.15 (VDD), U11.8 (VDD_IO), U11.15 (VDD), U12.8 (VDD_IO), U12.15 (VDD), U13.8 (VDD_IO), U13.15 (VDD), U19.8 (VDD_IO), U19.15 (VDD); also elsewhere on the board
GND: C3.2, C4.2, C5.2, C6.2, C7.2, C8.2, C9.2, C10.2, C11.2, C12.2, C13.2, C14.2, C15.2, C16.2, C17.2, C18.2, C19.2, C20.2, C21.2, C22.2, C23.2, C24.2, C44.2, C45.2, U3.4 (N/C), U3.9 (N/C), U3.10 (N/C), U3.11 (A1), U3.12 (A0), U3.13 (VSS), U3.14 (N/C), U3.16 (N/C), U4.4 (N/C), U4.9 (N/C), U4.10 (N/C), U4.11 (A1), U4.12 (A0), U4.13 (VSS), U4.14 (N/C), U4.16 (N/C), U5.4 (N/C), U5.9 (N/C), U5.10 (N/C), U5.11 (A1), U5.12 (A0), U5.13 (VSS), U5.14 (N/C), U5.16 (N/C), U6.4 (N/C), U6.9 (N/C), U6.10 (N/C), U6.11 (A1), U6.12 (A0), U6.13 (VSS), U6.14 (N/C), U6.16 (N/C), U7.4 (N/C), U7.9 (N/C), U7.10 (N/C), U7.11 (A1), U7.12 (A0), U7.13 (VSS), U7.14 (N/C), U7.16 (N/C), U8.4 (N/C), U8.9 (N/C), U8.10 (N/C), U8.11 (A1), U8.12 (A0), U8.13 (VSS), U8.14 (N/C), U8.16 (N/C), U9.4 (N/C), U9.9 (N/C), U9.10 (N/C), U9.11 (A1), U9.12 (A0), U9.13 (VSS), U9.14 (N/C), U9.16 (N/C), U10.4 (N/C), U10.9 (N/C), U10.10 (N/C), U10.11 (A1), U10.12 (A0), U10.13 (VSS), U10.14 (N/C), U10.16 (N/C), U11.4 (N/C), U11.9 (N/C), U11.10 (N/C), U11.11 (A1), U11.12 (A0), U11.13 (VSS), U11.14 (N/C), U11.16 (N/C), U12.4 (N/C), U12.9 (N/C), U12.10 (N/C), U12.11 (A1), U12.12 (A0), U12.13 (VSS), U12.14 (N/C), U12.16 (N/C), U13.4 (N/C), U13.9 (N/C), U13.10 (N/C), U13.11 (A1), U13.12 (A0), U13.13 (VSS), U13.14 (N/C), U13.16 (N/C), U19.4 (N/C), U19.9 (N/C), U19.10 (N/C), U19.11 (A1), U19.12 (A0), U19.13 (VSS), U19.14 (N/C), U19.16 (N/C); also elsewhere on the board

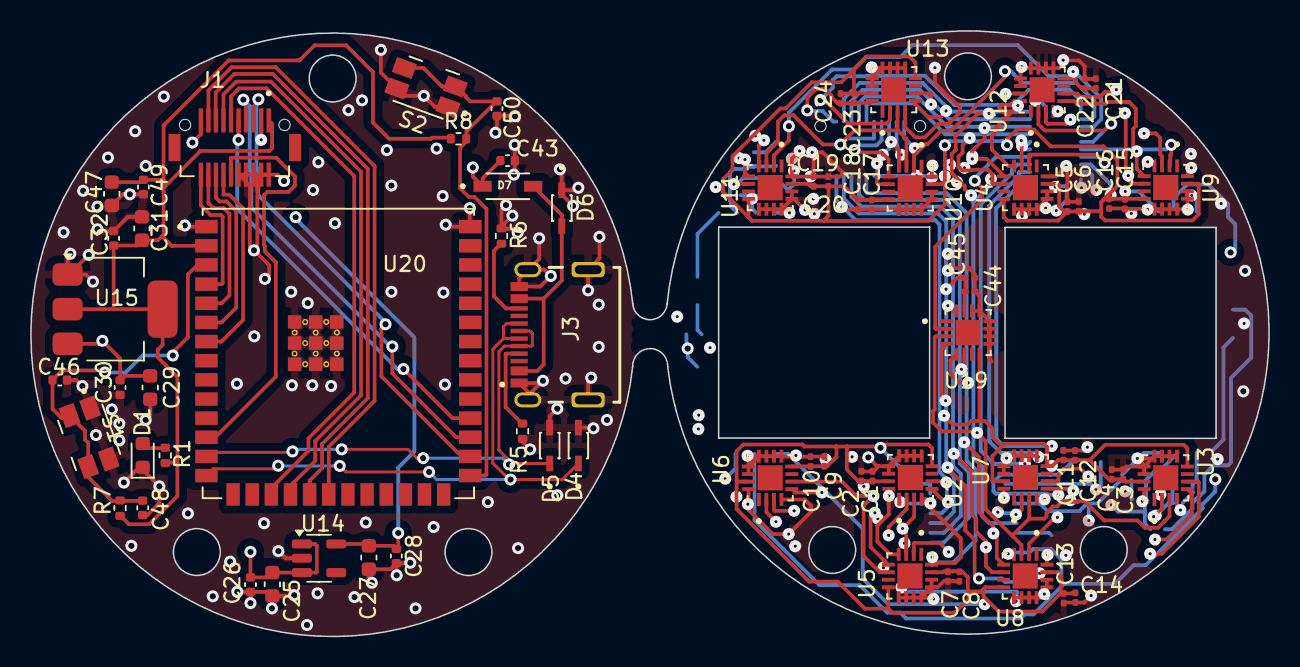
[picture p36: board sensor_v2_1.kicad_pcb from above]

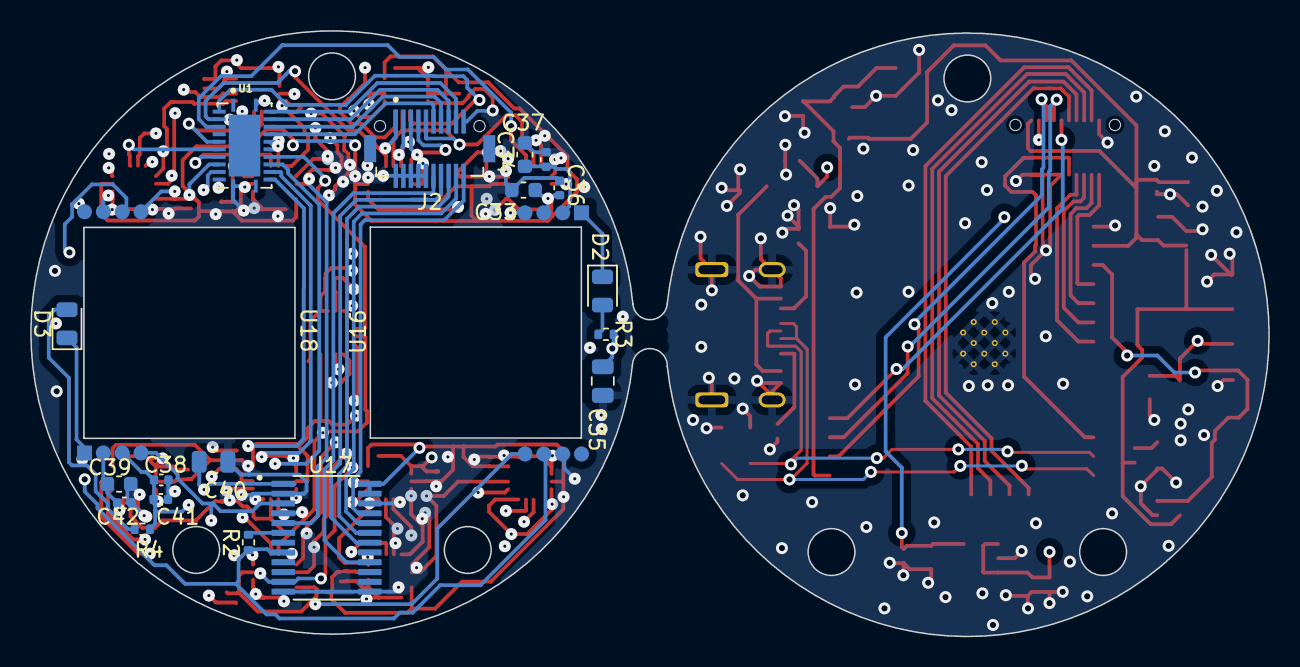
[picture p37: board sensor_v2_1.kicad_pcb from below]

Board: 4 copper layers, 82.1 x 40.2 mm, 90 parts (20 on the bottom side), 62 nets.

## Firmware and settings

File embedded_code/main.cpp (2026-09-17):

#include <Arduino.h>
#include <SPI.h>
#include "SPI_PAW3335.h"
#include "hall_sensor.h"

const String sensor_name = "sensor_1";

#define MOSI_PIN 7
#define MISO_PIN 8
#define SCLK_PIN 4
#define CS_PIN_1   5 // 5, 6 xs
#define CS_PIN_2   6 // 5, 6 xs

PAW3335 sensor(2000000, SCLK_PIN, MISO_PIN, MOSI_PIN, CS_PIN_1, CS_PIN_2);

#define SCLK_PIN_hall 37
#define MISO_PIN_hall 35
#define MOSI_PIN_hall 36
#define A0_PIN_hall 12
#define A1_PIN_hall 11
#define A2_PIN_hall 10
#define A3_PIN_hall 9

HALL_SENSOR hall_sensor(1000000, SCLK_PIN_hall, MISO_PIN_hall, MOSI_PIN_hall, A0_PIN_hall, A1_PIN_hall, A2_PIN_hall, A3_PIN_hall);

bool handshake = false;

void setup() {
  pinMode(6, OUTPUT);
  digitalWrite(6, HIGH);
  // Start the Serial Monitor
  Serial.begin(115200);
  delay(2000);
  Serial.println("Init mouse sensors");
  sensor.init();
  sensor.start_up();
  Serial.println("Init hall sensors");
  hall_sensor.init();
  Serial.println("setup done");
}



void readSerial(String& msg){
  while (Serial.available()) {
    //handshake = false; 
    // get the new byte:
    char ch = Serial.read();
    msg += ch;
    // end of user input
    if (ch == '\n') {
      if (msg[0] == 'n'){
        handshake = true;
      }else{
        handshake = false;
      }
      msg = "";
      return;
    }
  }
}

struct Packet {
  int16_t dx0, dy0;
  int16_t dx1, dy1;
  int16_t hall[13][4]; // x,y,z,T
};

String msg = "";


int rate_hz = 250;   // <-- change here
int period_ms = 1000 / rate_hz;

void loop() {
  static unsigned long last = 0;
  unsigned long now = millis();
  if (now - last < period_ms) return;
  last = now;
  
  Packet pkt;
  auto d0 = sensor.read_delta(0);
  auto d1 = sensor.read_delta(1);
  pkt.dx0 = d0.dx;
  pkt.dy0 = d0.dy;
  pkt.dx1 = d1.dx;
  pkt.dy1 = d1.dy;

  auto hall_data = hall_sensor.read_all_sensors();
  for (int i=0; i<13; i++) {
    pkt.hall[i][0] = hall_data[i].x;
    pkt.hall[i][1] = hall_data[i].y;
    pkt.hall[i][2] = hall_data[i].z;
    pkt.hall[i][3] = hall_data[i].T;
  }
  if (handshake == false){
    Serial.write(0xAA);
    Serial.write((uint8_t*)&pkt, sizeof(pkt));
  }else{
    // send name of sensor 
    Serial.println(""); 
    Serial.print("n");
    Serial.print("/t");
    Serial.println(sensor_name); 
  }
    
  readSerial(msg);
  
}

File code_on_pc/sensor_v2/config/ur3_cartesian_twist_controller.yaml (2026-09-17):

ur3_cartesian_twist_controller:
  type: "velocity_controllers/CartesianTwistController"
  base_link: "base_link"
  end_effector_link: "tool0"
  
  # Parameters for velocity scaling and limits
  linear:
    x:
      max_velocity: 0.5 # m/s
    y:
      max_velocity: 0.5 # m/s
    z:
      max_velocity: 0.5 # m/s
  angular:
    x:
      max_velocity: 1.0 # rad/s
    y:
      max_velocity: 1.0 # rad/s
    z:
      max_velocity: 1.0 # rad/s

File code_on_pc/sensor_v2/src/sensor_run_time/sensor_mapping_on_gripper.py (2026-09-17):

#!/usr/bin/env python3
import rospy
import torch
import numpy as np
from torch import nn
from sensor_msgs.msg import Image
from std_msgs.msg import Float32MultiArray
from sensor_v2.msg import TactileSensor 
from sensor_v2.msg import TactileVelSensor 
from geometry_msgs.msg import WrenchStamped, Vector3 
torch.set_num_threads(1)
torch.set_num_interop_threads(1)


import time

def build_matrix(theta1, theta2, r1, r2):
    """
    Returns the 4x3 matrix:
        [ Rz^T(theta1)   Rz^T(theta1) p_perp(r1) ]
        [ Rz^T(theta2)   Rz^T(theta2) p_perp(r2) ]

    r1, r2 are 2-element vectors/lists/arrays like [x, y]
    """
    # Rotation transpose in 2D
    def RzT(theta):
        c, s = np.cos(theta), np.sin(theta)
        return np.array([[ c,  s],
                         [-s,  c]])

    # p_perp([x, y]) = [-y, x]
    def p_perp(r):
        x, y = r
        return np.array([-y, x])

    R1 = RzT(theta1)
    R2 = RzT(theta2)

    p1 = p_perp(r1)
    p2 = p_perp(r2)

    # Each block: 2x2 and 2x1 → stack into 4x3
    upper = np.hstack([R1, (R1 @ p1).reshape(2,1)])
    lower = np.hstack([R2, (R2 @ p2).reshape(2,1)])

    return np.vstack([upper, lower])


def make_circular_mask(size=32):
    """Return a (size*size,) mask with 1 inside circle, 0 outside."""
    y, x = np.ogrid[:size, :size]
    center = (size - 1) / 2
    radius = size / 2
    dist = np.sqrt((x - center) ** 2 + (y - center) ** 2)
    mask = (dist <= radius).astype(np.float32)
    return mask

# ------------------- Model Definition -------------------
class MultiOutputMLP(nn.Module):
    def __init__(self, in_dim=36, hidden_dim=256, thickness_dim=(32,32), scalar_dim=6, hall13_dim=3):
        super().__init__()
        self.thickness_shape = thickness_dim  
        # Encoder
        self.encoder = nn.Sequential(
            nn.Linear(in_dim, hidden_dim),
            nn.ReLU(),
            nn.Dropout(0.2),
            nn.Linear(hidden_dim, hidden_dim),
            nn.ReLU(),
            nn.Dropout(0.2),
            nn.Linear(hidden_dim, hidden_dim),
            nn.ReLU()
        )

        self.thickness_head = nn.Sequential(
            nn.Linear(hidden_dim, 64 * 4 * 4),
            nn.ReLU(),
            nn.Unflatten(1, (64, 4, 4)),          # (batch, 64, 4, 4)
            nn.ConvTranspose2d(64, 32, kernel_size=4, stride=2, padding=1),  # → 8x8
            nn.ReLU(),
            nn.ConvTranspose2d(32, 16, kernel_size=4, stride=2, padding=1),  # → 16x16
            nn.ReLU(),
            nn.ConvTranspose2d(16, 8, kernel_size=4, stride=2, padding=1),   # → 32x32
            nn.ReLU(),
            nn.Conv2d(8, 1, kernel_size=3, padding=1),                       # (batch, 1, 32, 32)
        )


        # Scalars + hall13
        self.scalars_head = nn.Linear(hidden_dim, scalar_dim)
        self.hall13_head = nn.Linear(hidden_dim, hall13_dim)

    def forward(self, x):
        z = self.encoder(x)

        # Thickness prediction
        t_pred = self.thickness_head(z)           
        t_pred = t_pred.view(z.size(0), -1)      
        

        # Scalars and hall13
        s_pred = self.scalars_head(z)
        h13_pred = self.hall13_head(z)

        return t_pred, s_pred, h13_pred


class SensorConfig:
    def __init__(self, sensor_nr):
        if sensor_nr == 1:
            self.cpmm1 = 216.29 # counts per mm
            self.cpmm2 = 212.73 
            self.px1 = -7.11
            self.py1 = 0.36
            self.omega1 = 1.52
            self.px2 = 8.41
            self.py2 = -0.17
            self.omega2 = -1.56
        else:
            self.cpmm1 = 185.63 # counts per mm
            self.cpmm2 = 197.04 
            self.px1 = -4.39
            self.py1 = -0.217
            self.omega1 = 1.379
            self.px2 = 8.36
            self.py2 = -0.16
            self.omega2 = -1.561

class VelocityMapping:
    def __init__(self, sensor_config, pub, sub_sample=1):
        self.last_t = rospy.Time.now().to_sec()
        self.delta_sum = np.array([[0], [0], [0], [0]])
        self.sub_sample = sub_sample
        self.cpmm = np.array([[sensor_config.cpmm1], [sensor_config.cpmm1], [sensor_config.cpmm2], [sensor_config.cpmm2]])
        self.mapping = build_matrix(theta1=sensor_config.omega1,
                                    theta2=sensor_config.omega2,
                                    r1=[sensor_config.px1, sensor_config.py1],
                                    r2=[sensor_config.px2, sensor_config.py2])
        self.mapping_pinv = np.linalg.pinv(self.mapping)
        self.pub = pub
        self.k = 0

    def callback(self, sensor_data):
        dx1 = sensor_data.mouse_sensor[0].x
        dy1 = sensor_data.mouse_sensor[0].y
        dx2 = sensor_data.mouse_sensor[1].x
        dy2 = sensor_data.mouse_sensor[1].y
        self.delta_sum += np.array([[dx1], [dy1], [dx2], [dy2]])
        self.k += 1
        if self.sub_sample <= self.k:
            delta_mm = self.delta_sum / self.cpmm
            t_now = sensor_data.header.stamp.to_sec()
            dt = (t_now - self.last_t)
            vel_mm_s = delta_mm/dt
            self.last_t = t_now
            self.k = 0
            self.delta_sum = np.array([[0], [0], [0], [0]])
            sensor_vel = self.mapping_pinv.dot(vel_mm_s)
            vel_msg = TactileVelSensor()
            vel_msg.header.stamp = sensor_data.header.stamp
            vel_msg.vx = sensor_vel[0, 0]/1e3
            vel_msg.vy = sensor_vel[1, 0]/1e3
            vel_msg.omega = sensor_vel[2, 0]
            self.pub.publish(vel_msg)
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

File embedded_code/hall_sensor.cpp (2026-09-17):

#include <Arduino.h>
#include <SPI.h>
#include "hall_sensor.h"


HALL_SENSOR::HALL_SENSOR(int spi_hz, int SCLK_PIN_, int MISO_PIN_, int MOSI_PIN_, int A0_PIN, int A1_PIN, int A2_PIN, int A3_PIN):
    spiSettings(spi_hz, MSBFIRST, SPI_MODE3),
    SCLK_PIN(SCLK_PIN_),
    MISO_PIN(MISO_PIN_),
    MOSI_PIN(MOSI_PIN_),
    A0_PIN(A0_PIN),
    A1_PIN(A1_PIN),
    A2_PIN(A2_PIN),
    A3_PIN(A3_PIN),
    Vspi(HSPI)
    {
        hallList = {{
                        {0, 0, 0, 0},
                        {1, 0, 0, 0},
                        {1, 1, 0, 0},
                        {0, 1, 0, 0},
                        {1, 0, 1, 0},
                        {1, 1, 1, 0},
                        {0, 1, 1, 0},
                        {0, 0, 0, 1},
                        {1, 0, 0, 1},
                        {0, 1, 0, 1},
                        {1, 0, 1, 1},
                        {0, 1, 1, 1},
                        {0, 0, 1, 1},
                        {1, 1, 1, 1}    
                    }};

};
    
void HALL_SENSOR::setHallCS(int cs){
    digitalWrite(A0_PIN, hallList[cs].A0);
    digitalWrite(A1_PIN, hallList[cs].A1);
    digitalWrite(A2_PIN, hallList[cs].A2);
    digitalWrite(A3_PIN, hallList[cs].A3);

}

void HALL_SENSOR::sendCommand(uint8_t *cmd, uint8_t cmdLength, uint8_t *response, uint8_t respLength, int cs) {
  setHallCS(cs+1);
  delayMicroseconds(6);
  
  

  for (int i = 0; i < cmdLength; i++) {
    Vspi.transfer(cmd[i]);
  }

  delayMicroseconds(6);

  for (int i = 0; i < respLength; i++) {
    response[i] = Vspi.transfer(0x00); // dummy write to read
  }

  delayMicroseconds(6);
  
  setHallCS(0);
}



void HALL_SENSOR::start_up(int cs){
    uint8_t resp[10];
    // === Step 1: Reset ===
    uint8_t rt_cmd[1] = { 0xF0 };
    sendCommand(rt_cmd, 1, resp, 1, cs+1);
    Serial.print("RT Status: 0x"); Serial.println(resp[0], HEX);
    delay(5);

    // === Step 2: Set COMM_MODE = 0b10 (SPI only) in register 0x01 ===
    Serial.println("Setting COMM_MODE = SPI only...");
    // This sets bits [3:2] = 0b10 → 0x08 in LSB
    uint8_t wr_comm_mode[] = { 0x60, 0x00, 0x00, 0x08, 0x04 };  // WR, access=0x00, data=0x0008, addr=0x01 << 2
    sendCommand(wr_comm_mode, 5, resp, 1, cs+1);
    Serial.print("WR Status: 0x"); Serial.println(resp[0], HEX);
    delay(2);

    // === Step 3: Start Single Measurement for ZYXT (all set) ===
    Serial.println("Sending SM (Single Measurement)...");
    uint8_t sm_cmd[] = { 0x3F, 0x0F };  // SM + ZYXT = 1111b
    sendCommand(sm_cmd, 2, resp, 1, cs+1);
    Serial.print("SM Status: 0x"); Serial.println(resp[0], HEX);
    delay(5);  // Wait for measurement to complete
    Serial.print("Started");
    Serial.println(cs+1);
}

void HALL_SENSOR::init(){

    pinMode(A0_PIN, OUTPUT);
    pinMode(A1_PIN, OUTPUT);
    pinMode(A2_PIN, OUTPUT);
    pinMode(A3_PIN, OUTPUT);
    Vspi.begin(SCLK_PIN, MISO_PIN, MOSI_PIN, 13);  // SPI pins: SCK, MISO, MOSI, CS
    Vspi.beginTransaction(spiSettings);  // Safe choice: 1 MHz
    setHallCS(0);
    delay(50); // Wait for sensor startup
    for (int i = 0; i<13; i++){
        start_up(i);
    }
    Serial.println("hall started");

}


std::array<hall_data_int_16, 13> HALL_SENSOR::read_all_sensors(){
    uint8_t smCmd[2] = {CMD_SM, 0x0F}; // Start Single Measurement XYZ + Temp
    uint8_t rmCmd[2] = {CMD_RM, 0x0F}; // Read Measurement result

    // start measurment on all sensors 
    for (int i = 0; i<13; i++){
        uint8_t result[9] = {0};
        sendCommand(smCmd, 2, result, 1, i);
    }

    delayMicroseconds(1000); // Wait for measurement to complete

    std::array<hall_data_int_16, 13> sensor_data;

    // read measurment on all sesnors
    for (int i = 0; i<13; i++){
        uint8_t result[9] = {0};
        sendCommand(rmCmd, 2, result, 9, i);

        int16_t x = (int16_t)((result[2] << 8) | result[3]);
        int16_t y = (int16_t)((result[4] << 8) | result[5]);
        int16_t z = (int16_t)((result[6] << 8) | result[7]);
        uint16_t t_raw = (int16_t)((result[0] << 8) | result[1]);
        /*
        float x_uT = x * 0.150f;
        float y_uT = y * 0.150f;
        float z_uT = z * 0.242f;
        float temp_C = ((float)t_raw - 46244.0f) / 45.2f + 25.0;

        sensor_data[i].x = x_uT;    // example values
        sensor_data[i].y = y_uT;
        sensor_data[i].z = z_uT;
        sensor_data[i].T = temp_C;
        */
        sensor_data[i].x = x;    // example values
        sensor_data[i].y = y;
        sensor_data[i].z = z;
        sensor_data[i].T = t_raw;
    }

    return sensor_data;

}
